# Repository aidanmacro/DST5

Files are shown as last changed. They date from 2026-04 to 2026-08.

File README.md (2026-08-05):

---
publishDate: YYYY-MM-DDT00:00:00Z

title: Low-Cost Breath Monitoring for Musicians Using the MYOSA Platform

excerpt: A portable, low-cost respiratory monitoring system for brass and wind musicians using the MYOSA development board, NDIR CO₂ sensing, and environmental measurements.

image: 

tags:
  - Embedded Systems
  - IoT
  - Music Technology
  - Respiratory Monitoring
  - MYOSA
---

> A low-cost embedded system providing objective, real-time respiratory feedback for musicians.

---

## Acknowledgements

---

## Overview

### Project Summary

### Problem Being Solved

### Project Objectives

---

## Demo / Examples

### Images

### Videos

---

## Features (Detailed)

### 1. MYOSA Embedded Platform

### 2. Breath Monitoring System

### 3. BMP180 Environmental Monitoring

### 4. Data Logging

### 5. User Interface

### 6. Low-Cost Design

### 7. Future Improvements

---

## Usage Instructions

### Hardware Setup

### Running the Software

### Example Code

## Tech Stack

---

## Requirements / Installation

### Hardware

### Software

## File Structure (Optional)

---

## License (Optional)

---

## Contribution Notes (Optional)

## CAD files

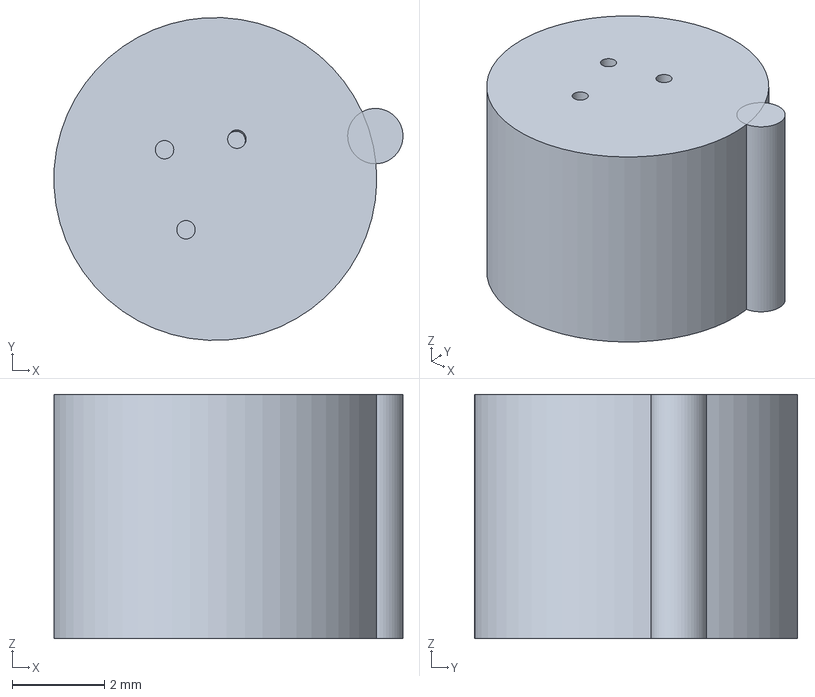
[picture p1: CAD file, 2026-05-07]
KiCAD/DST5_custom_library/3dmodels/TO46 Sheath.step
7.57 x 6.99 x 5.30 mm

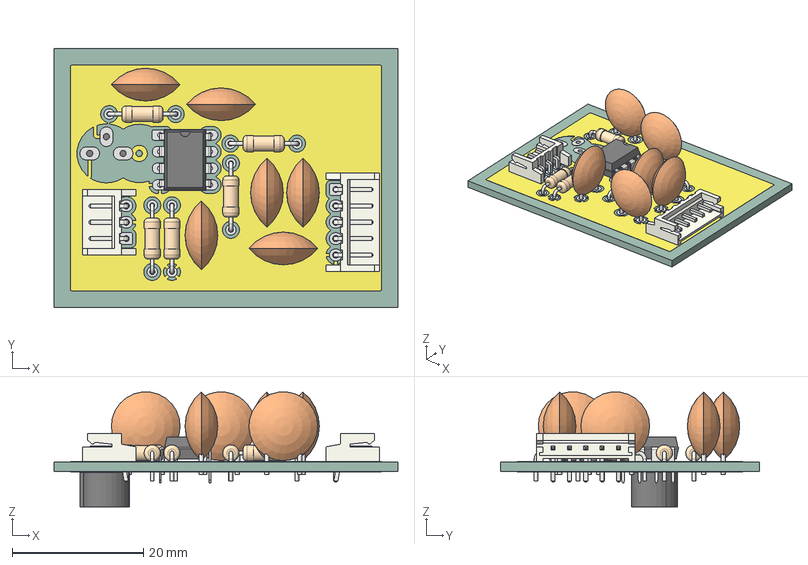
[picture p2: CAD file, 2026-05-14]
KiCAD/projects/photodiode TIA circuit/photodiode_tia_circuit/.step
52.5 x 39.5 x 17.5 mm
DIP-8_W7.62mm
JST_EH_S5B-EH_1x05_P2.50mm_Horizontal
C_Disc_D10.5mm_W5.0mm_P5.00mm x 6
R_Axial_DIN0207_L6.3mm_D2.5mm_P10.16mm_Horizontal x 5
JST_EH_S3B-EH_1x03_P2.50mm_Horizontal
TO46 Sheath
photodiode_tia_circuit_copper
photodiode_tia_circuit_pad
photodiode_tia_circuit_via
photodiode_tia_circuit_PCB

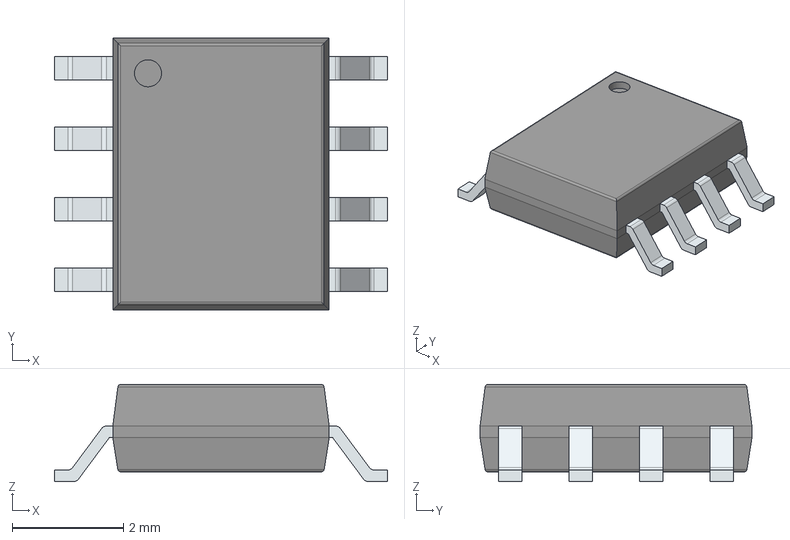
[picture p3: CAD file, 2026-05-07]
KiCAD/DST5_custom_library/3dmodels/STCS05DR.stp
6.00 x 4.90 x 1.75 mm
PinsArrayLR

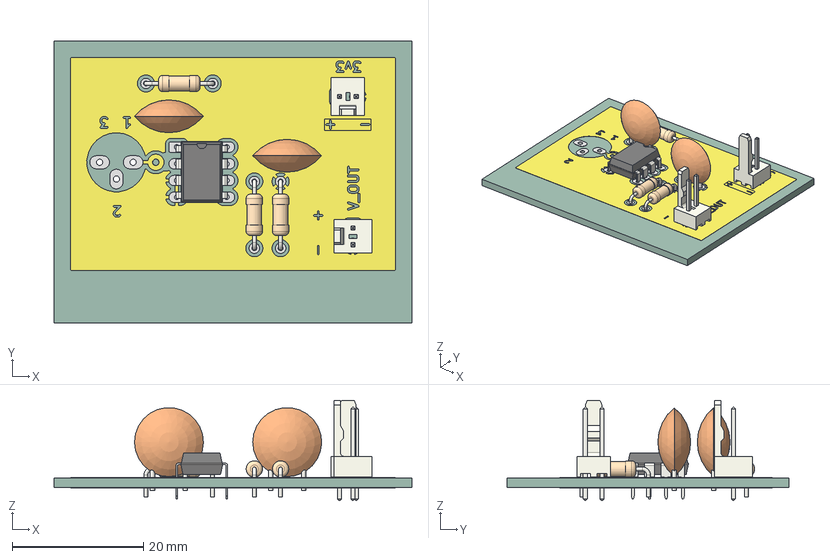
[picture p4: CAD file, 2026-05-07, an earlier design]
KiCAD/projects/photodiode TIA circuit/photodiode_tia_circuit/old_version.step
54.5 x 43.0 x 15.3 mm
DIP-8_W7.62mm
C_Disc_D10.5mm_W5.0mm_P5.00mm x 2
R_Axial_DIN0207_L6.3mm_D2.5mm_P10.16mm_Horizontal x 3
Molex_KK-254_AE-6410-02A_1x02_P2.54mm_Vertical x 2
photodiode_tia_circuit_copper
photodiode_tia_circuit_pad
photodiode_tia_circuit_via
photodiode_tia_circuit_PCB

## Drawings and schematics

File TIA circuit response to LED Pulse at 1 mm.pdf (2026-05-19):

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

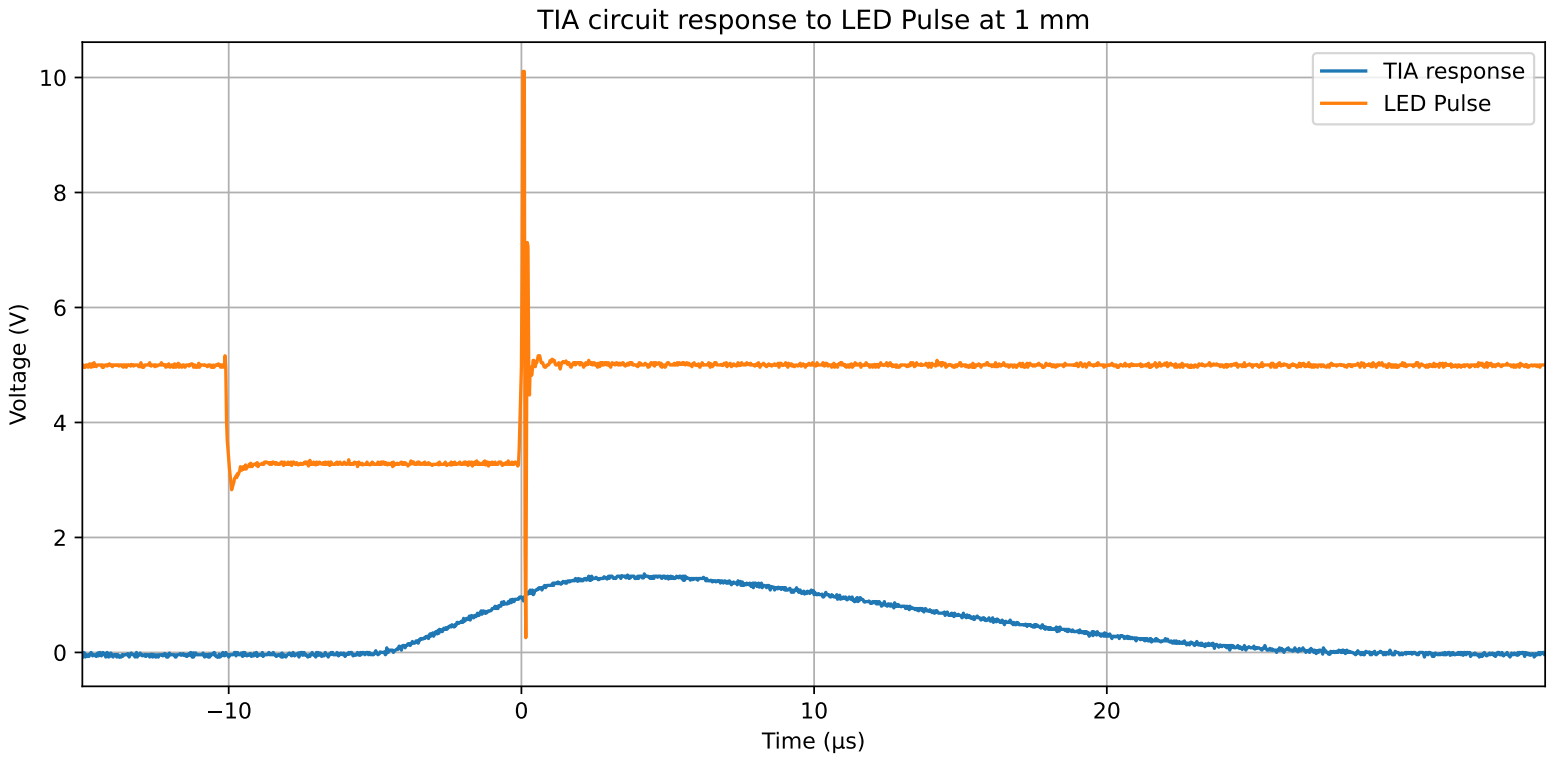
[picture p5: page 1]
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

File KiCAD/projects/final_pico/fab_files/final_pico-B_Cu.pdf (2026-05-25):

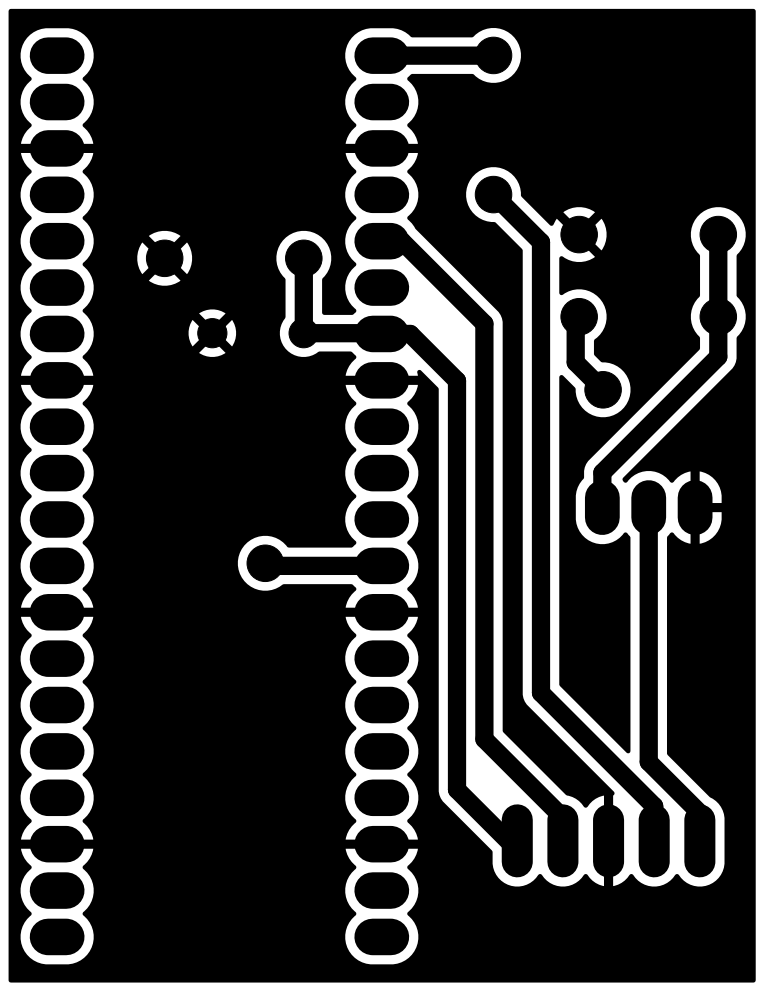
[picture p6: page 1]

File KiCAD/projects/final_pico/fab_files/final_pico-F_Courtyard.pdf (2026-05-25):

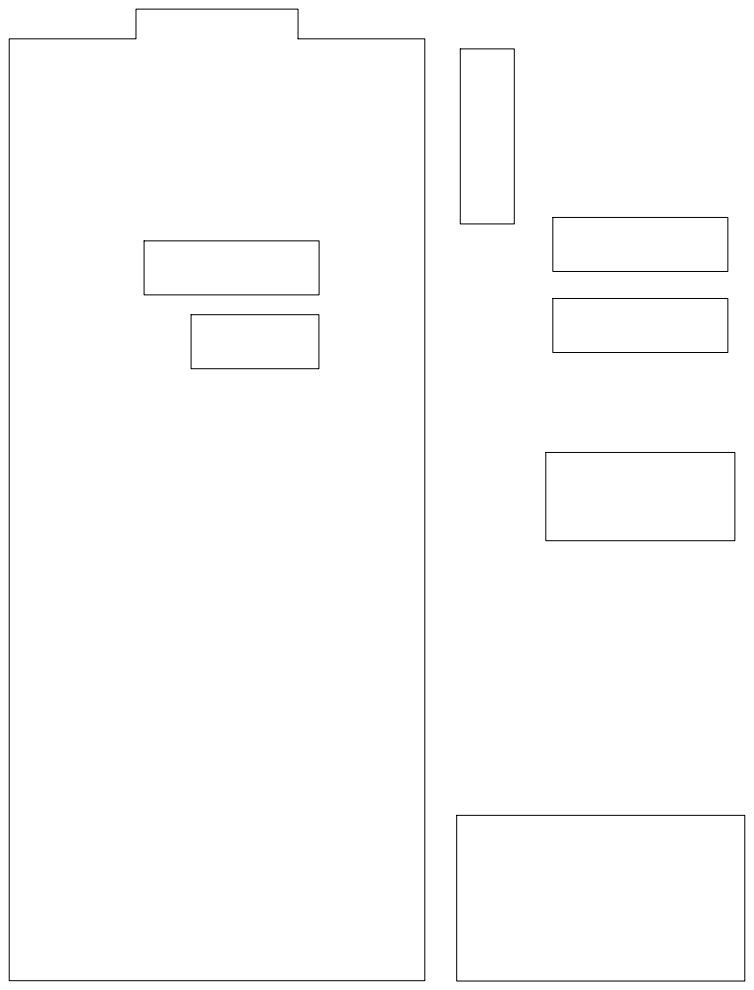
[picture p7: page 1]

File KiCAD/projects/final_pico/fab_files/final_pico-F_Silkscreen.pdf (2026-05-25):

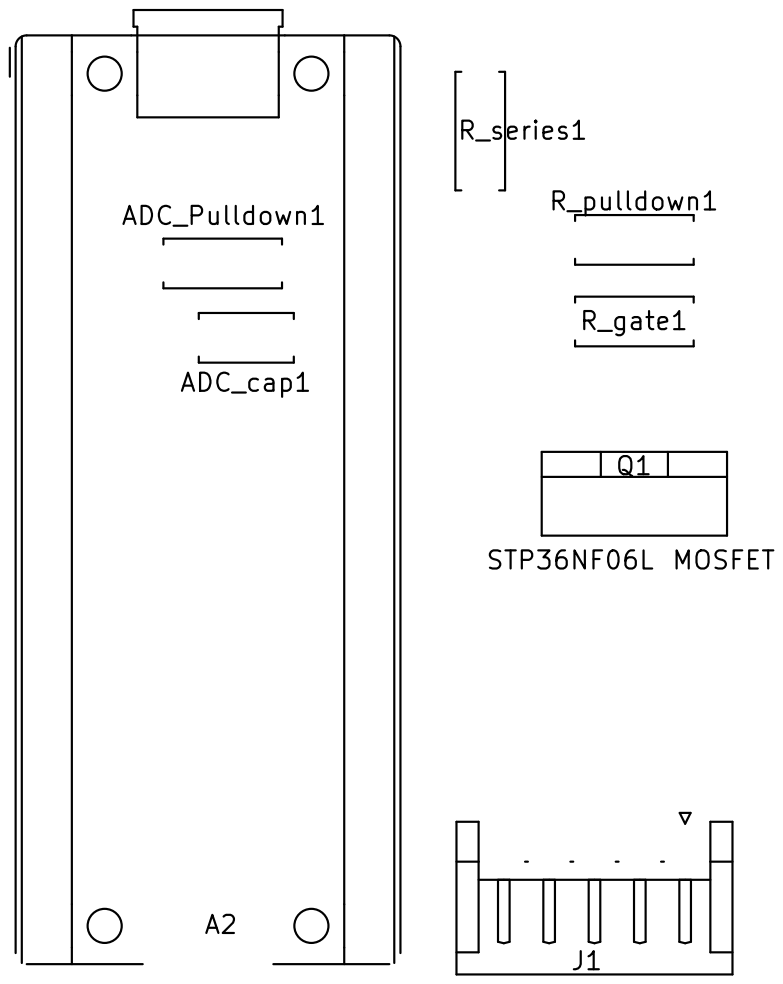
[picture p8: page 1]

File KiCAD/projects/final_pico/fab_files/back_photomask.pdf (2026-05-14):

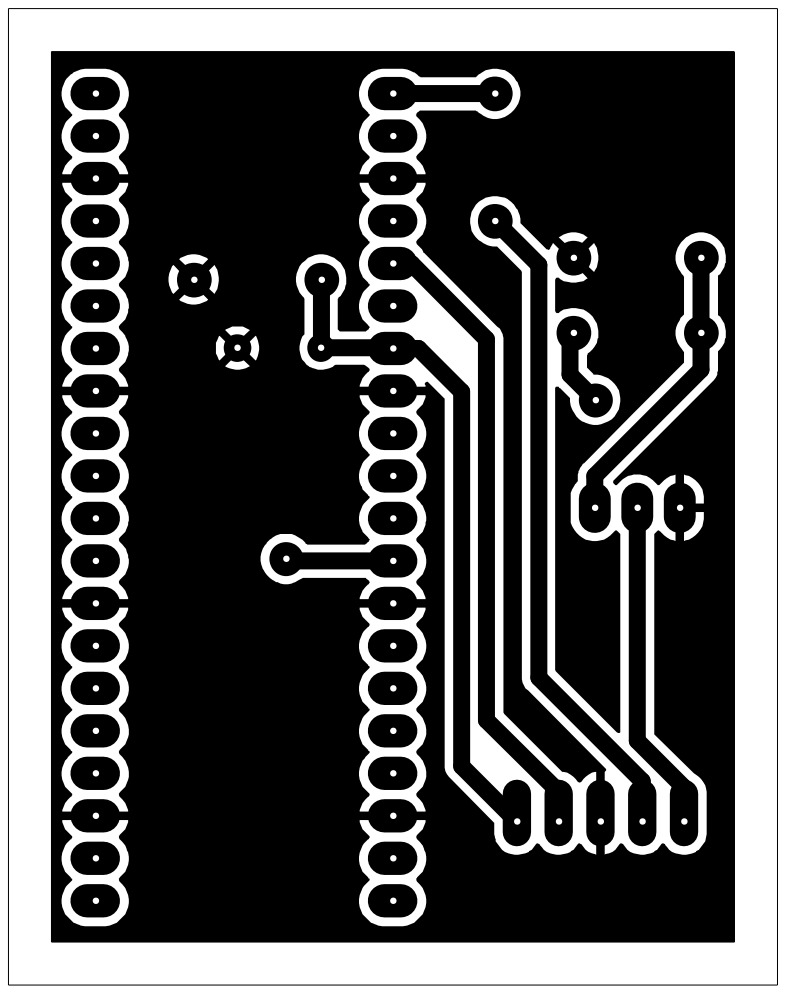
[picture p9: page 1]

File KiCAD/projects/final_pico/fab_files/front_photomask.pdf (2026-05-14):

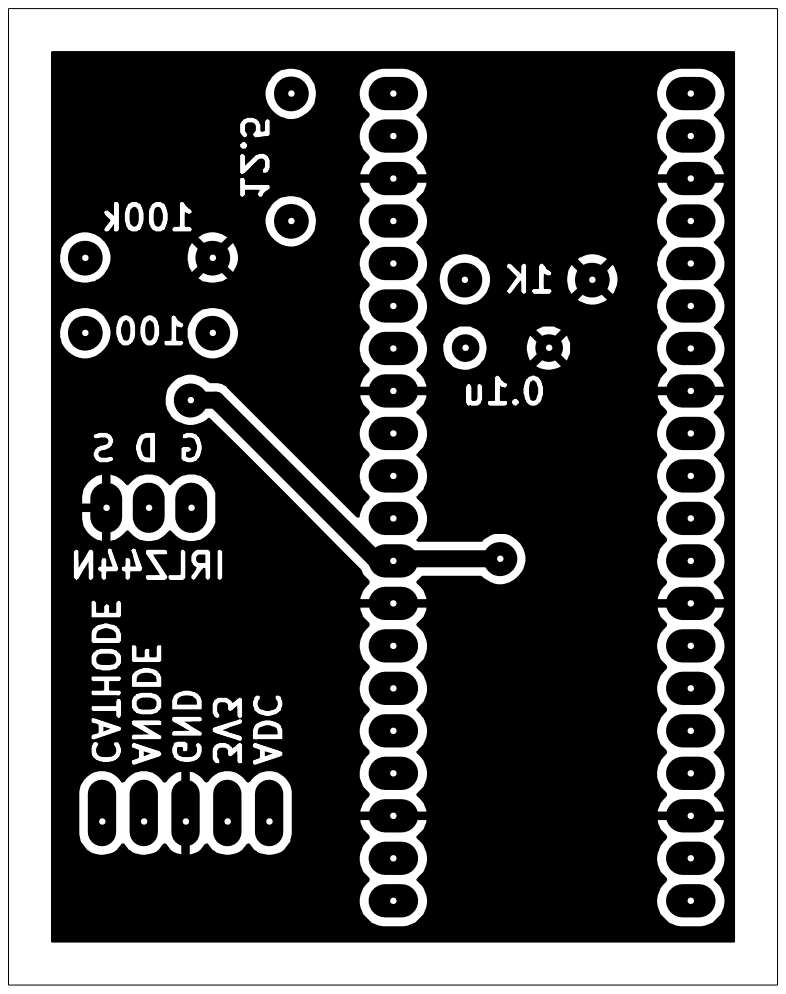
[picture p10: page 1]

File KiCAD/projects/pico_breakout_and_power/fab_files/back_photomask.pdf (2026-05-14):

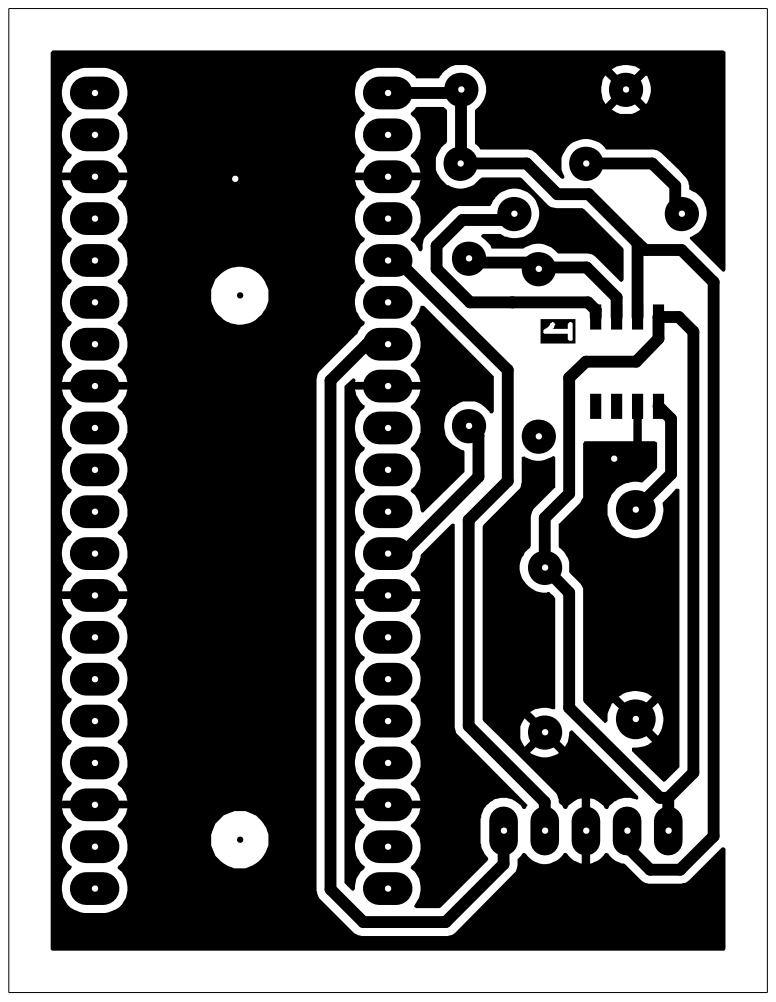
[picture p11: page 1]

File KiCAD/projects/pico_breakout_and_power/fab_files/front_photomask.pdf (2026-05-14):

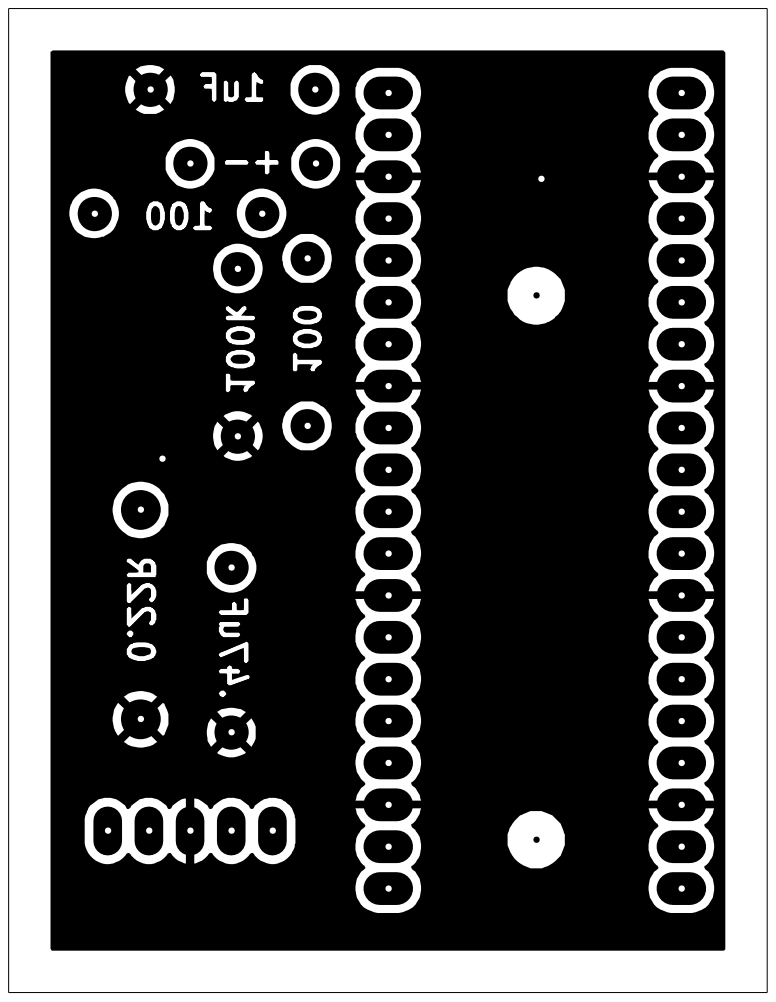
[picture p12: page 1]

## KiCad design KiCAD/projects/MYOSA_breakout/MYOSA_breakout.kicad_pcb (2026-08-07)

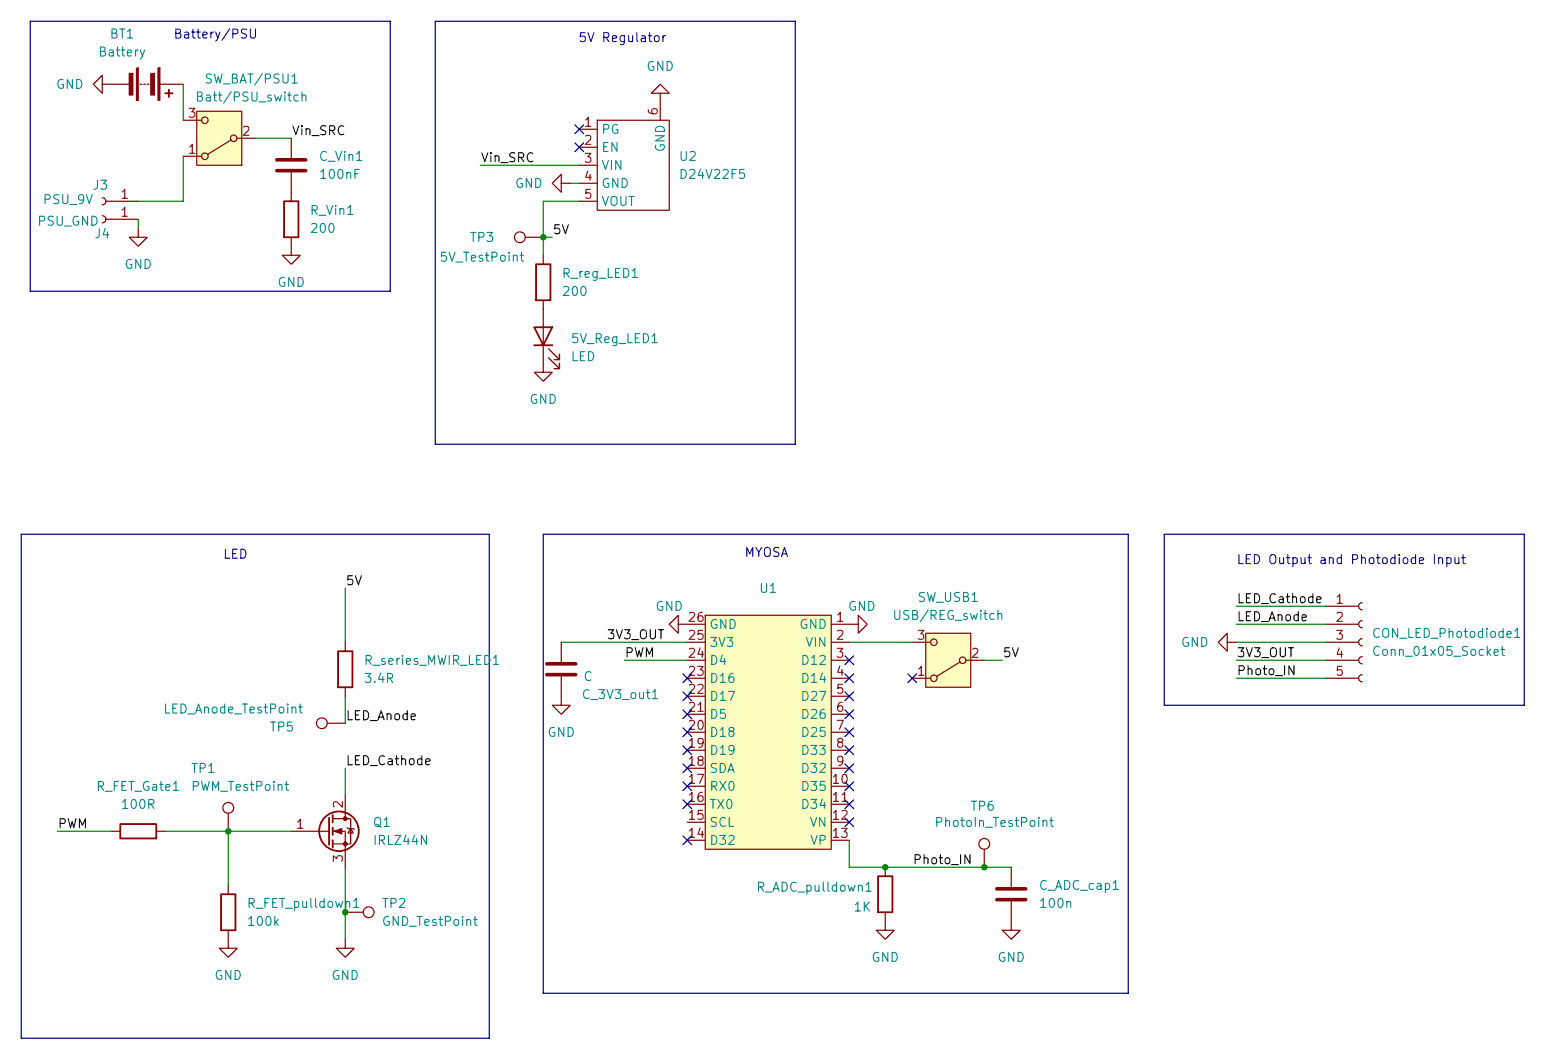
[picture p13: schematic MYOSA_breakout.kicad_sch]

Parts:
5V_Reg_LED1: LED; LED_D5.0mm
BT1: Battery; BatteryHolder_MPD_BA9VPC_1xPP3
CON_LED_Photodiode1: Conn_01x05_Socket; JST_EH_S5B-EH_1x05_P2.50mm_Horizontal
C_3V3_out1: C; C_Disc_D5.0mm_W2.5mm_P5.00mm
C_ADC_cap1: 100n; C_Disc_D5.0mm_W2.5mm_P5.00mm
C_Vin1: 100nF; C_Disc_D5.0mm_W2.5mm_P5.00mm
J3: PSU_9V; Banana_Jack_1Pin
J4: PSU_GND; Banana_Jack_1Pin
Q1: IRLZ44N; TO-220-3_Vertical
R_ADC_pulldown1: 1K; R_Axial_DIN0207_L6.3mm_D2.5mm_P7.62mm_Horizontal
R_FET_Gate1: 100R; R_Axial_DIN0207_L6.3mm_D2.5mm_P7.62mm_Horizontal
R_FET_pulldown1: 100k; R_Axial_DIN0207_L6.3mm_D2.5mm_P7.62mm_Horizontal
R_Vin1: 200; R_Axial_DIN0207_L6.3mm_D2.5mm_P7.62mm_Horizontal
R_reg_LED1: 200; R_Axial_DIN0207_L6.3mm_D2.5mm_P7.62mm_Horizontal
R_series_MWIR_LED1: 3.4R; R_Axial_DIN0207_L6.3mm_D2.5mm_P7.62mm_Horizontal
SW_BAT/PSU1: Batt/PSU_switch; SW_Slide-03_Wuerth-WS-SLTV_10x2.5x6.4_P2.54mm
SW_USB1: USB/REG_switch; SW_Slide-03_Wuerth-WS-SLTV_10x2.5x6.4_P2.54mm
TP1: PWM_TestPoint; TestPoint_Loop_D2.50mm_Drill1.85mm
TP2: GND_TestPoint; TestPoint_Loop_D2.50mm_Drill1.85mm
TP3: 5V_TestPoint; TestPoint_Loop_D2.50mm_Drill1.85mm
TP5: LED_Anode_TestPoint; TestPoint_Loop_D2.50mm_Drill1.85mm
TP6: PhotoIn_TestPoint; TestPoint_Loop_D2.50mm_Drill1.85mm
U1: MYOSA_ESP-32
U2: D24V22F5

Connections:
/3V3_OUT: CON_LED_Photodiode1.4, C_3V3_out1.1, U1.25 (3V3)
/5V: R_reg_LED1.1, R_series_MWIR_LED1.1, SW_USB1.2 (B), TP3.1, U2.5 (VOUT)
/LED_Anode: CON_LED_Photodiode1.2, R_series_MWIR_LED1.2, TP5.1
/LED_Cathode: CON_LED_Photodiode1.1, Q1.2 (D)
/PWM: R_FET_Gate1.1, U1.24 (D4)
/Photo_IN: CON_LED_Photodiode1.5, C_ADC_cap1.1, R_ADC_pulldown1.1, TP6.1, U1.13 (VP)
/Vin_SRC: C_Vin1.1, SW_BAT/PSU1.2 (B), U2.3 (VIN)
GND: 5V_Reg_LED1.1 (K), BT1.2 (-), CON_LED_Photodiode1.3, C_3V3_out1.2, C_ADC_cap1.2, J4.1, Q1.3 (S), R_ADC_pulldown1.2, R_FET_pulldown1.2, R_Vin1.2, TP2.1, U1.1 (GND), U1.26 (GND), U2.4 (GND), U2.6 (GND)
unnamed: 5V_Reg_LED1.2 (A), R_reg_LED1.2
unnamed: BT1.1 (+), SW_BAT/PSU1.3 (C)
unnamed: C_Vin1.2, R_Vin1.1
unnamed: J3.1, SW_BAT/PSU1.1 (A)
unnamed: Q1.1 (G), R_FET_Gate1.2, R_FET_pulldown1.1, TP1.1
unnamed: SW_USB1.3 (C), U1.2 (VIN)

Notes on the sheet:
LED
LED Output and Photodiode Input
MYOSA
Battery/PSU
5V Regulator

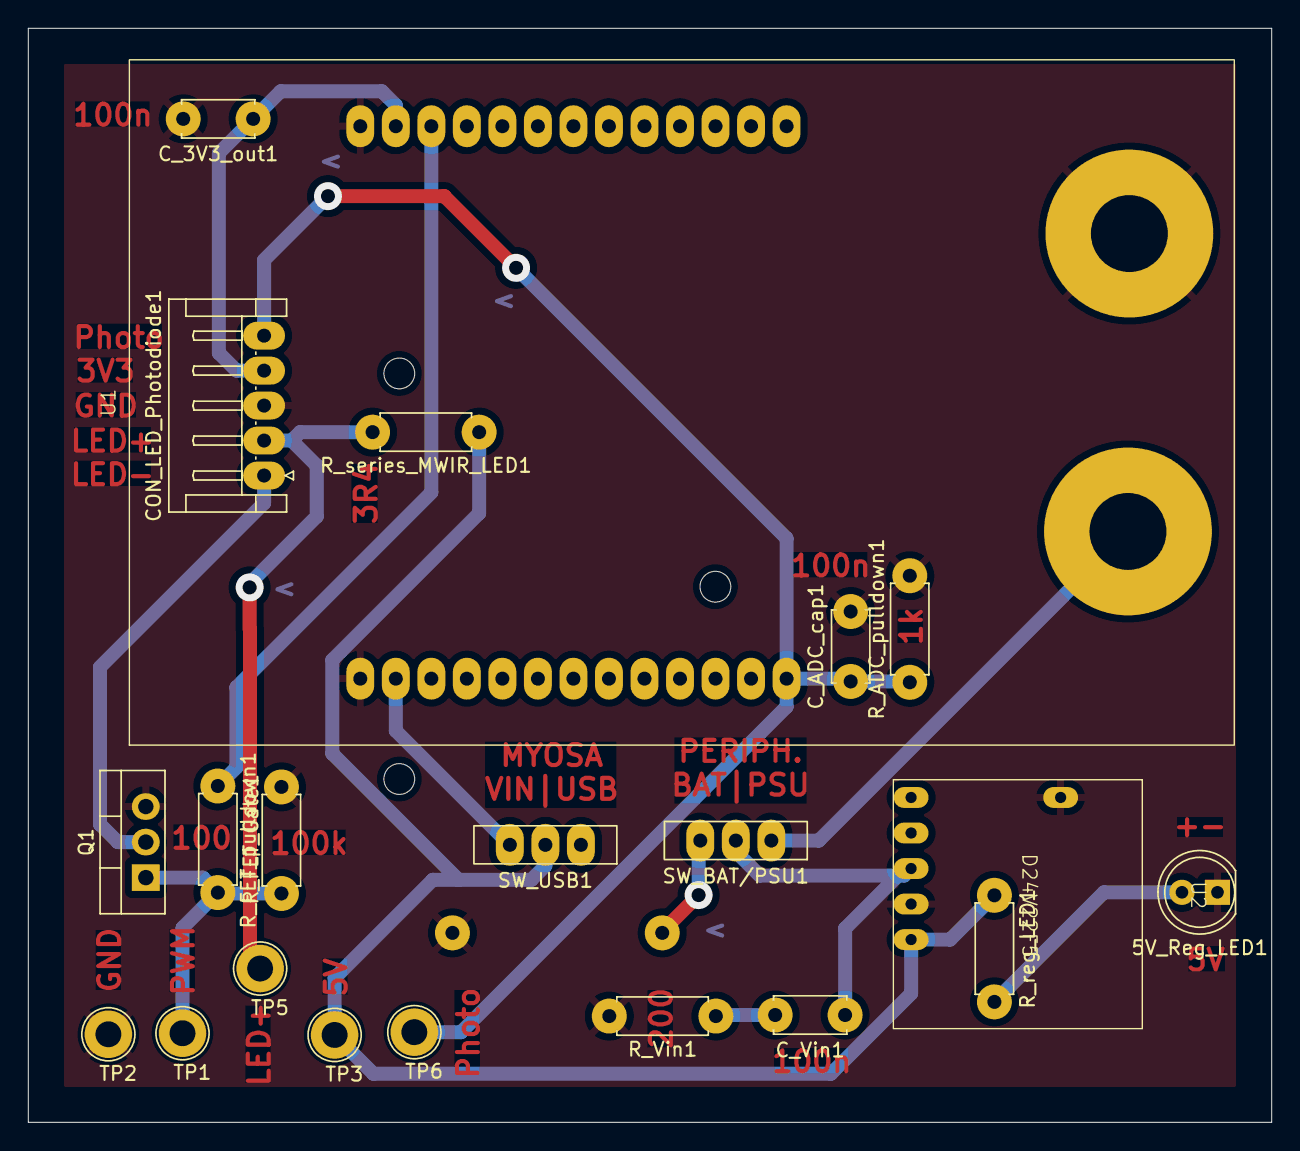
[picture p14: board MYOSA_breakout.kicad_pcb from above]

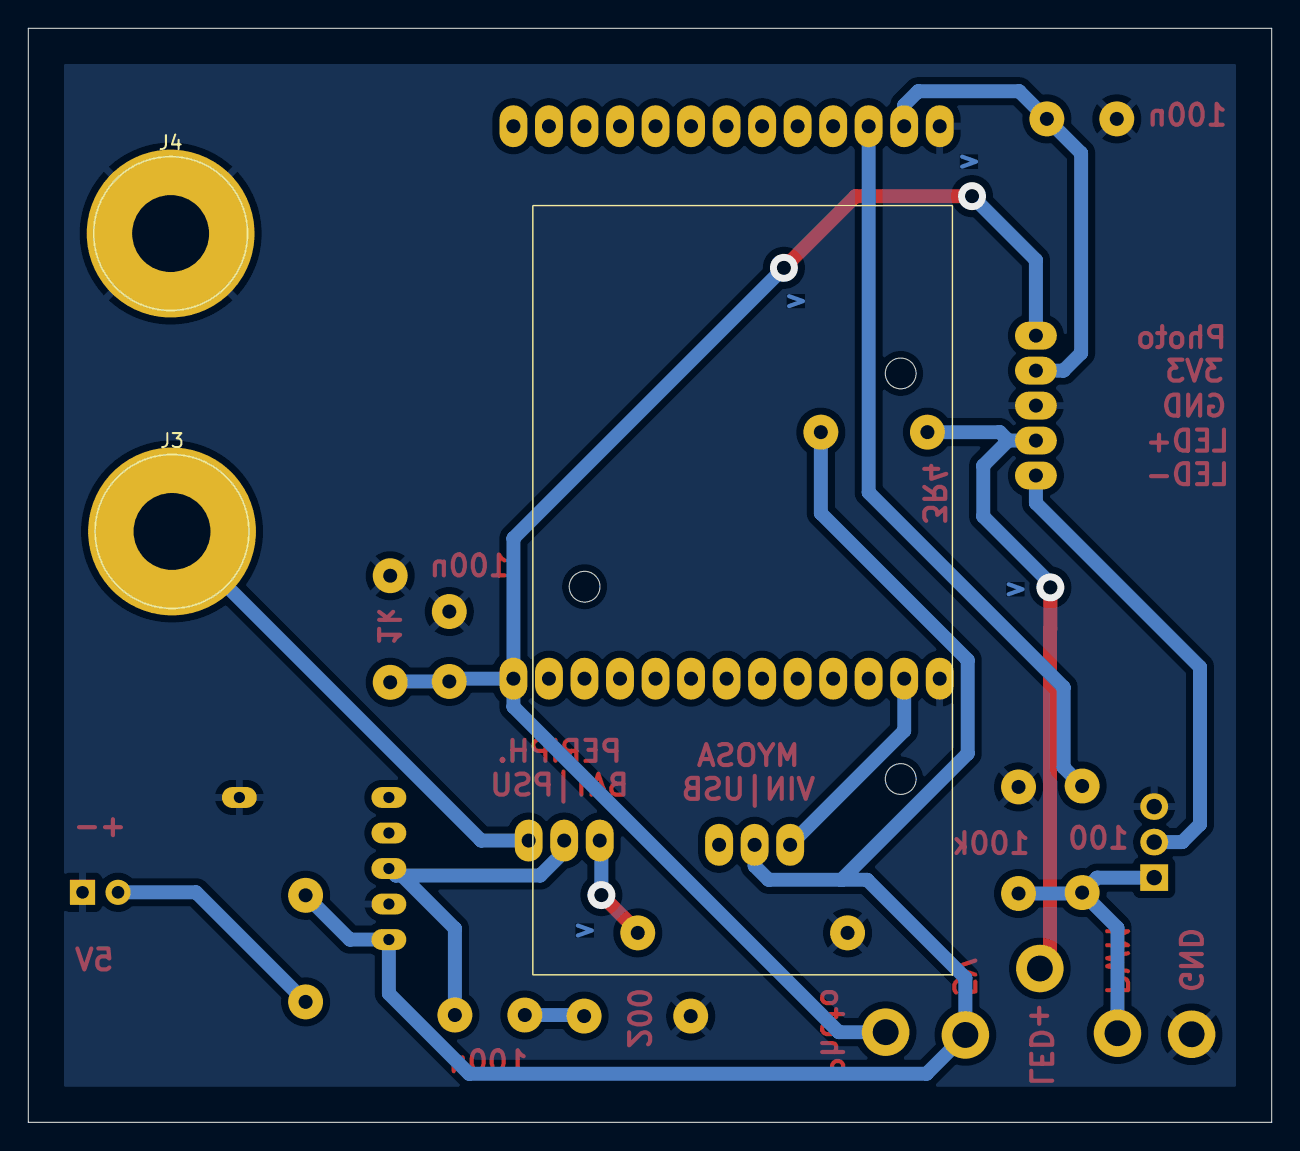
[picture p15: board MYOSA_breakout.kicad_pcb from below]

Board: 2 copper layers, 88.9 x 78.2 mm, 24 parts (3 on the bottom side), 14 nets.

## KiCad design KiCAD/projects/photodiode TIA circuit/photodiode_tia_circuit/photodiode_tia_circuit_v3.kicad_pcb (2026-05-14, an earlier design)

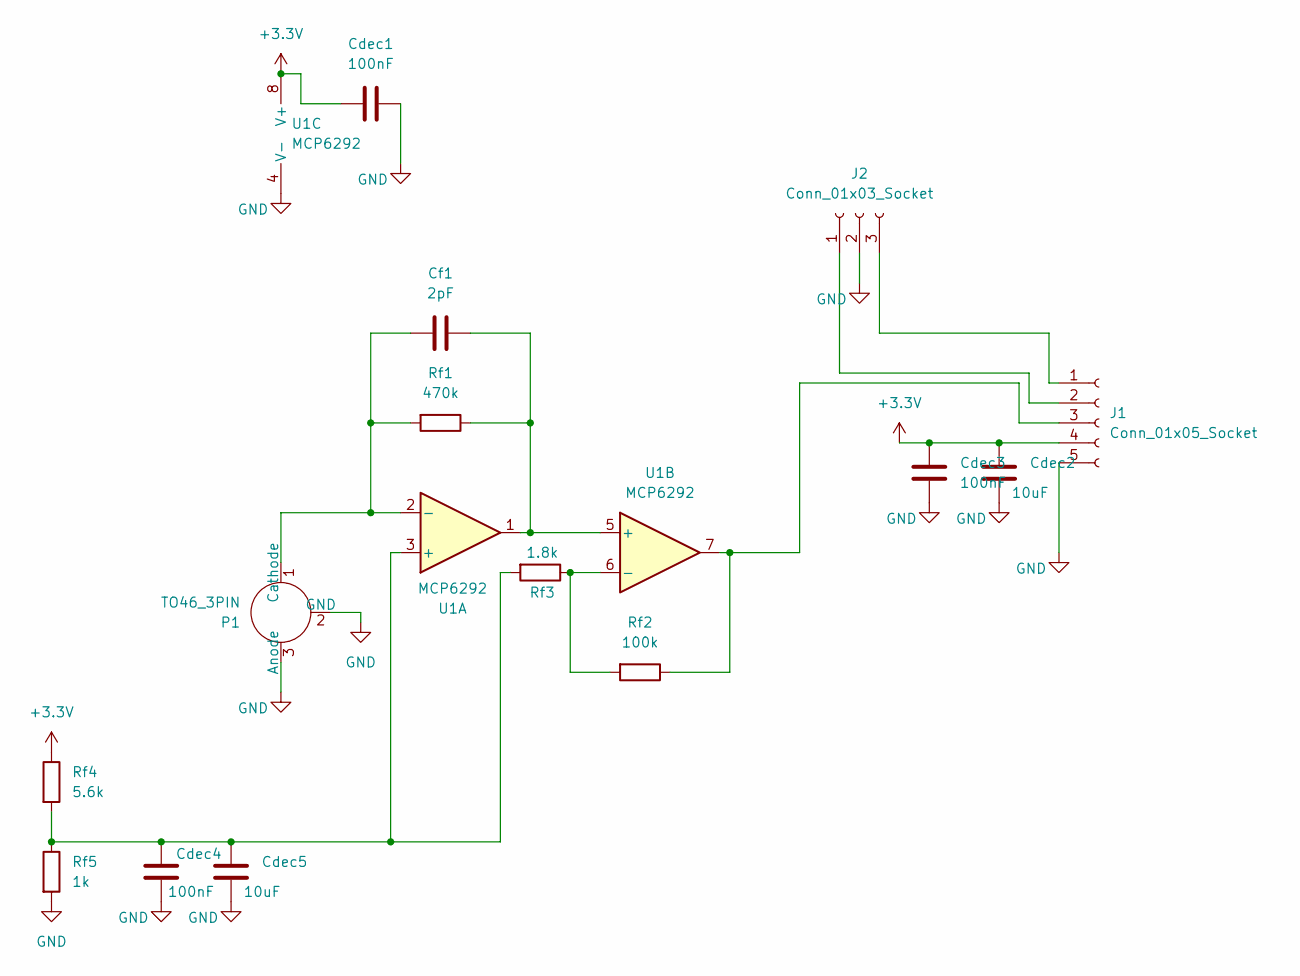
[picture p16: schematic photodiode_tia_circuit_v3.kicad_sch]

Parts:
Cdec1, Cdec3, Cdec4: 100nF; C_Disc_D10.5mm_W5.0mm_P5.00mm
Cdec2, Cdec5: 10uF; C_Disc_D10.5mm_W5.0mm_P5.00mm
Cf1: 2pF; C_Disc_D10.5mm_W5.0mm_P5.00mm
J1: Conn_01x05_Socket; JST_EH_S5B-EH_1x05_P2.50mm_Horizontal
J2: Conn_01x03_Socket; JST_EH_S3B-EH_1x03_P2.50mm_Horizontal
P1: TO46_3PIN
Rf1: 470k; R_Axial_DIN0207_L6.3mm_D2.5mm_P10.16mm_Horizontal
Rf2: 100k; R_Axial_DIN0207_L6.3mm_D2.5mm_P10.16mm_Horizontal
Rf3: 1.8k; R_Axial_DIN0207_L6.3mm_D2.5mm_P10.16mm_Horizontal
Rf4: 5.6k; R_Axial_DIN0207_L6.3mm_D2.5mm_P10.16mm_Horizontal
Rf5: 1k; R_Axial_DIN0207_L6.3mm_D2.5mm_P10.16mm_Horizontal
U1: MCP6292; DIP-8_W7.62mm_LongPads

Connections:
+3.3V: Cdec1.1, Cdec2.2, Cdec3.2, J1.4, Rf4.1, U1.8 (V+)
GND: Cdec1.2, Cdec2.1, Cdec3.1, Cdec4.1, Cdec5.1, J1.5, J2.2, P1.2 (GND), P1.3 (Anode), Rf5.2, U1.4 (V-)
unnamed: J1.1, J2.3
unnamed: J1.2, J2.1
unnamed: J1.3, Rf2.1, U1.7
unnamed: Cf1.1, P1.1 (Cathode), Rf1.2, U1.2 (-)
unnamed: Cdec4.2, Cdec5.2, Rf3.2, Rf4.2, Rf5.1, U1.3 (+)
unnamed: Cf1.2, Rf1.1, U1.1, U1.5 (+)
unnamed: Rf2.2, Rf3.1, U1.6 (-)

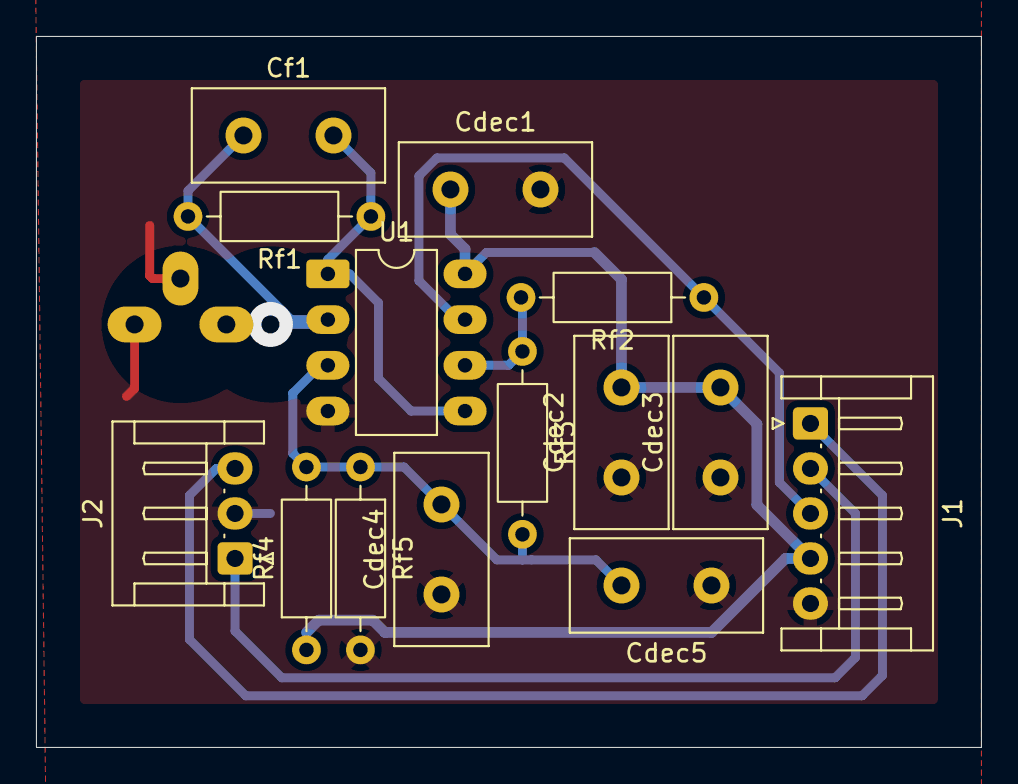
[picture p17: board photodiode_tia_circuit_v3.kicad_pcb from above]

Board: 2 copper layers, 52.5 x 39.5 mm, 15 parts (1 on the bottom side), 9 nets.

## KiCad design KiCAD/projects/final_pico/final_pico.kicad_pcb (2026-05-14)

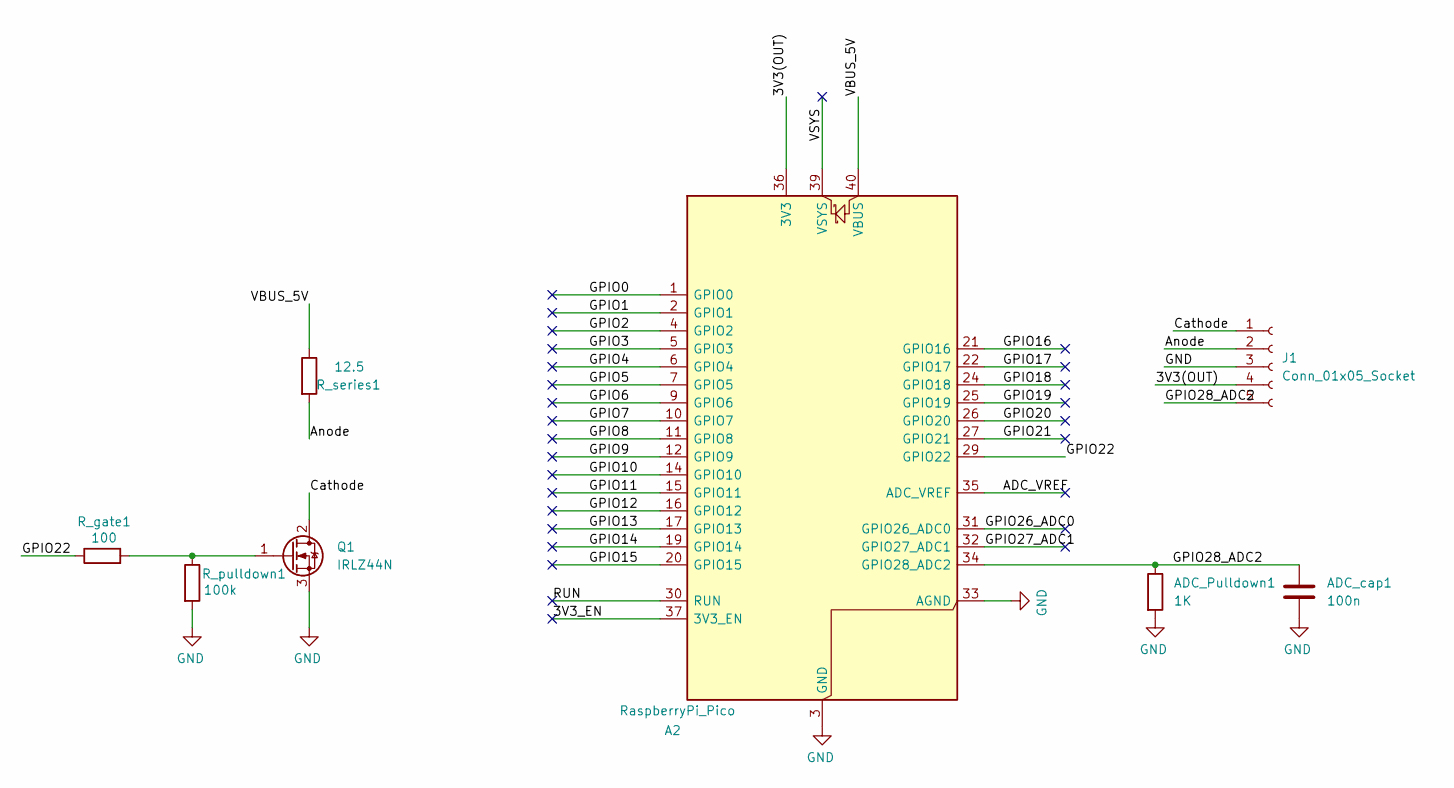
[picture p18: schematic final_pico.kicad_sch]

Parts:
A2: RaspberryPi_Pico; RaspberryPi_Pico_Common_THT
ADC_Pulldown1: 1K; R_Axial_DIN0207_L6.3mm_D2.5mm_P7.62mm_Horizontal
ADC_cap1: 100n; C_Disc_D5.0mm_W2.5mm_P5.00mm
J1: Conn_01x05_Socket; JST_EH_S5B-EH_1x05_P2.50mm_Horizontal
Q1: IRLZ44N; TO-220-3_Vertical
R_gate1: 100; R_Axial_DIN0207_L6.3mm_D2.5mm_P7.62mm_Horizontal
R_pulldown1: 100k; R_Axial_DIN0207_L6.3mm_D2.5mm_P7.62mm_Horizontal
R_series1: 12.5; R_Axial_DIN0207_L6.3mm_D2.5mm_P7.62mm_Horizontal

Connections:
/3V3(OUT): A2.36 (3V3), J1.4
/3V3_EN: A2.37 (3V3_EN)
/ADC_VREF: A2.35 (ADC_VREF)
/Anode: J1.2, R_series1.2
/Cathode: J1.1, Q1.2 (D)
/GPIO0: A2.1 (GPIO0)
/GPIO1: A2.2 (GPIO1)
/GPIO2: A2.4 (GPIO2)
/GPIO3: A2.5 (GPIO3)
/GPIO4: A2.6 (GPIO4)
/GPIO5: A2.7 (GPIO5)
/GPIO6: A2.9 (GPIO6)
/GPIO7: A2.10 (GPIO7)
/GPIO8: A2.11 (GPIO8)
/GPIO9: A2.12 (GPIO9)
/GPIO10: A2.14 (GPIO10)
/GPIO11: A2.15 (GPIO11)
/GPIO12: A2.16 (GPIO12)
/GPIO13: A2.17 (GPIO13)
/GPIO14: A2.19 (GPIO14)
/GPIO15: A2.20 (GPIO15)
/GPIO16: A2.21 (GPIO16)
/GPIO17: A2.22 (GPIO17)
/GPIO18: A2.24 (GPIO18)
/GPIO19: A2.25 (GPIO19)
/GPIO20: A2.26 (GPIO20)
/GPIO21: A2.27 (GPIO21)
/GPIO22: A2.29 (GPIO22), R_gate1.1
/GPIO26_ADC0: A2.31 (GPIO26_ADC0)
/GPIO27_ADC1: A2.32 (GPIO27_ADC1)
/GPIO28_ADC2: A2.34 (GPIO28_ADC2), ADC_Pulldown1.1, ADC_cap1.1, J1.5
/RUN: A2.30 (RUN)
/VBUS_5V: A2.40 (VBUS), R_series1.1
/VSYS: A2.39 (VSYS)
GND: A2.3 (GND), A2.8 (GND), A2.13 (GND), A2.18 (GND), A2.23 (GND), A2.28 (GND), A2.33 (AGND), A2.38 (GND), ADC_Pulldown1.2, ADC_cap1.2, J1.3, Q1.3 (S), R_pulldown1.2
unnamed: Q1.1 (G), R_gate1.2, R_pulldown1.1

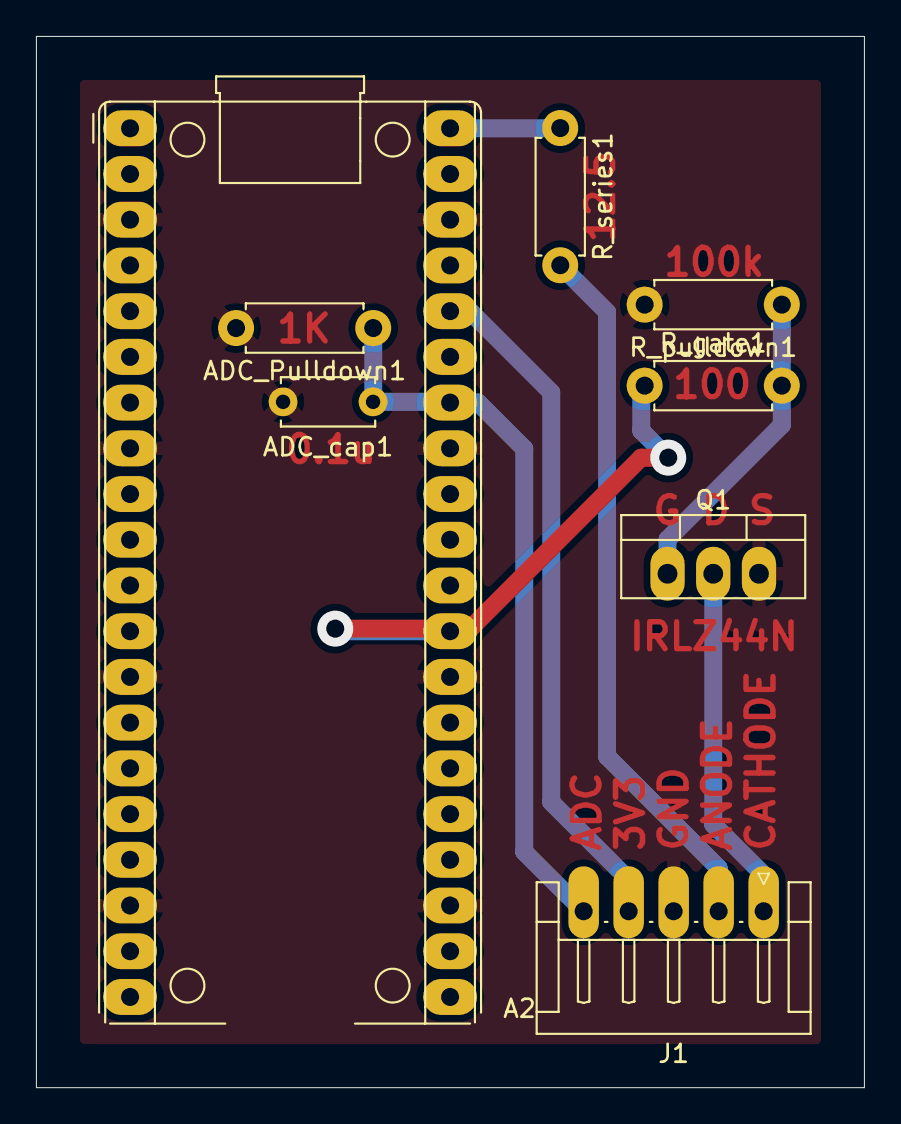
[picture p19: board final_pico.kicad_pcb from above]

Board: 2 copper layers, 46.0 x 58.4 mm, 8 parts (0 on the bottom side), 8 nets.

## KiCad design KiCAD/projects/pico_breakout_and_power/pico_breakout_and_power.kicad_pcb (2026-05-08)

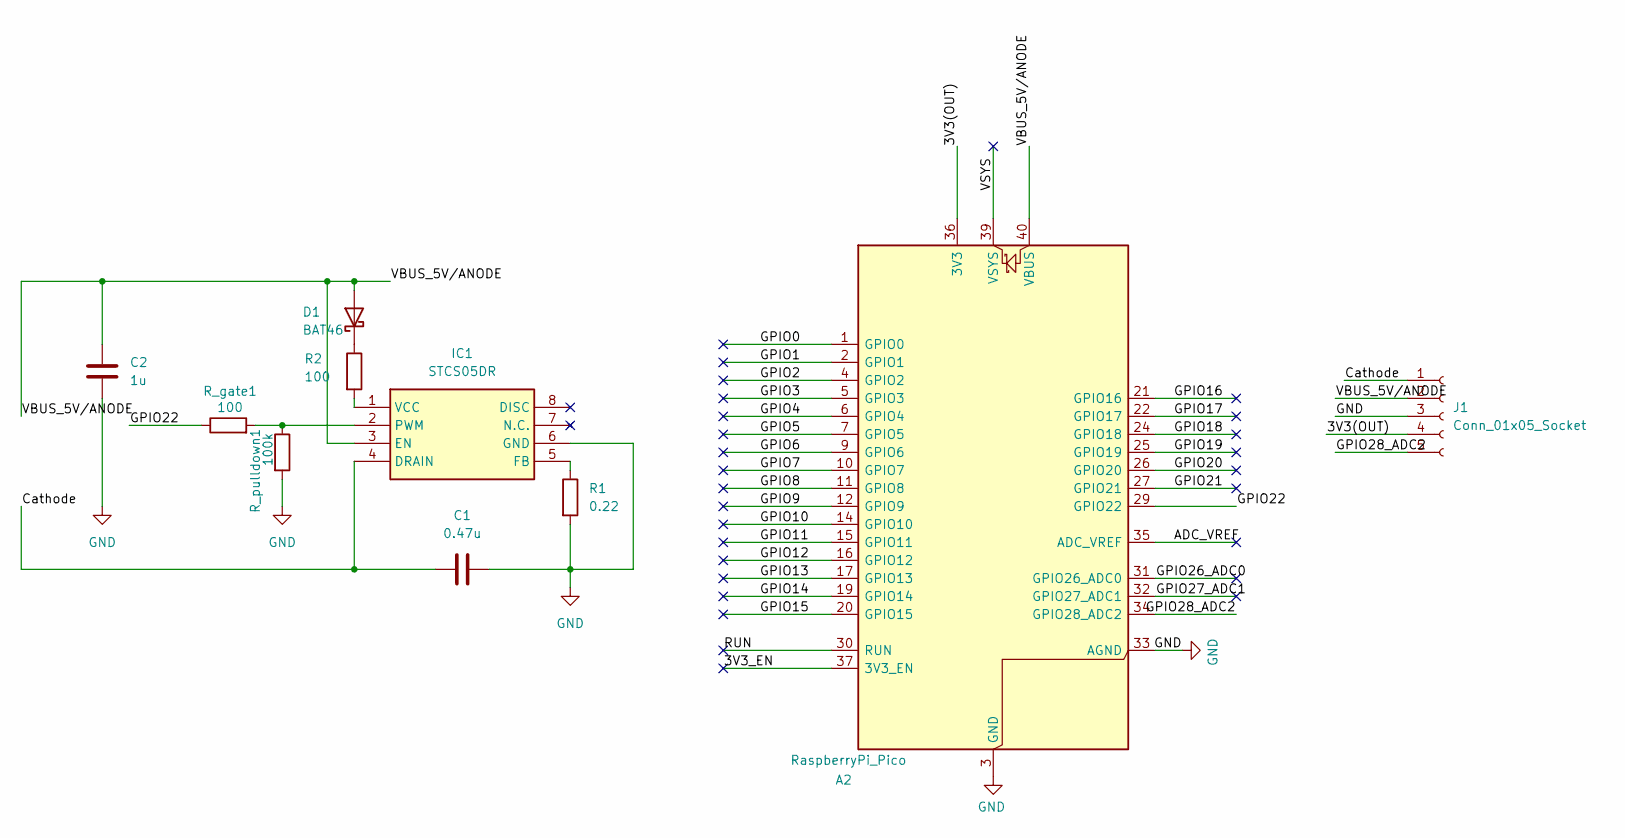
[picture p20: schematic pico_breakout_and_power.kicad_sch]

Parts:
A2: RaspberryPi_Pico; RaspberryPi_Pico_Common_THT
C1: 0.47u; C_Disc_D10.5mm_W5.0mm_P10.00mm
C2: 1u; C_Disc_D10.5mm_W5.0mm_P10.00mm
D1: BAT46; D_DO-35_SOD27_P7.62mm_Horizontal
IC1: STCS05DR; SOIC127P600X175-8N; Mouser Part Number 511-STCS05DR
J1: Conn_01x05_Socket; JST_EH_S5B-EH_1x05_P2.50mm_Horizontal
R1: 0.22; R_Axial_DIN0411_L9.9mm_D3.6mm_P12.70mm_Horizontal
R2: 100; R_Axial_DIN0207_L6.3mm_D2.5mm_P10.16mm_Horizontal
R_gate1: 100; R_Axial_DIN0207_L6.3mm_D2.5mm_P10.16mm_Horizontal
R_pulldown1: 100k; R_Axial_DIN0207_L6.3mm_D2.5mm_P10.16mm_Horizontal

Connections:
/3V3(OUT): A2.36 (3V3), J1.4
/3V3_EN: A2.37 (3V3_EN)
/ADC_VREF: A2.35 (ADC_VREF)
/Cathode: C1.1, IC1.4 (DRAIN), J1.1
/GPIO0: A2.1 (GPIO0)
/GPIO1: A2.2 (GPIO1)
/GPIO2: A2.4 (GPIO2)
/GPIO3: A2.5 (GPIO3)
/GPIO4: A2.6 (GPIO4)
/GPIO5: A2.7 (GPIO5)
/GPIO6: A2.9 (GPIO6)
/GPIO7: A2.10 (GPIO7)
/GPIO8: A2.11 (GPIO8)
/GPIO9: A2.12 (GPIO9)
/GPIO10: A2.14 (GPIO10)
/GPIO11: A2.15 (GPIO11)
/GPIO12: A2.16 (GPIO12)
/GPIO13: A2.17 (GPIO13)
/GPIO14: A2.19 (GPIO14)
/GPIO15: A2.20 (GPIO15)
/GPIO16: A2.21 (GPIO16)
/GPIO17: A2.22 (GPIO17)
/GPIO18: A2.24 (GPIO18)
/GPIO19: A2.25 (GPIO19)
/GPIO20: A2.26 (GPIO20)
/GPIO21: A2.27 (GPIO21)
/GPIO22: A2.29 (GPIO22), R_gate1.1
/GPIO26_ADC0: A2.31 (GPIO26_ADC0)
/GPIO27_ADC1: A2.32 (GPIO27_ADC1)
/GPIO28_ADC2: A2.34 (GPIO28_ADC2), J1.5
/RUN: A2.30 (RUN)
/VBUS_5V/ANODE: A2.40 (VBUS), C2.1, D1.2 (A), IC1.3 (EN), J1.2
/VSYS: A2.39 (VSYS)
GND: A2.3 (GND), A2.8 (GND), A2.13 (GND), A2.18 (GND), A2.23 (GND), A2.28 (GND), A2.33 (AGND), A2.38 (GND), C1.2, C2.2, IC1.6 (GND), J1.3, R1.2, R_pulldown1.2
unnamed: D1.1 (K), R2.1
unnamed: IC1.5 (FB), R1.1
unnamed: IC1.2 (PWM), R_gate1.2, R_pulldown1.1
unnamed: IC1.1 (VCC), R2.2

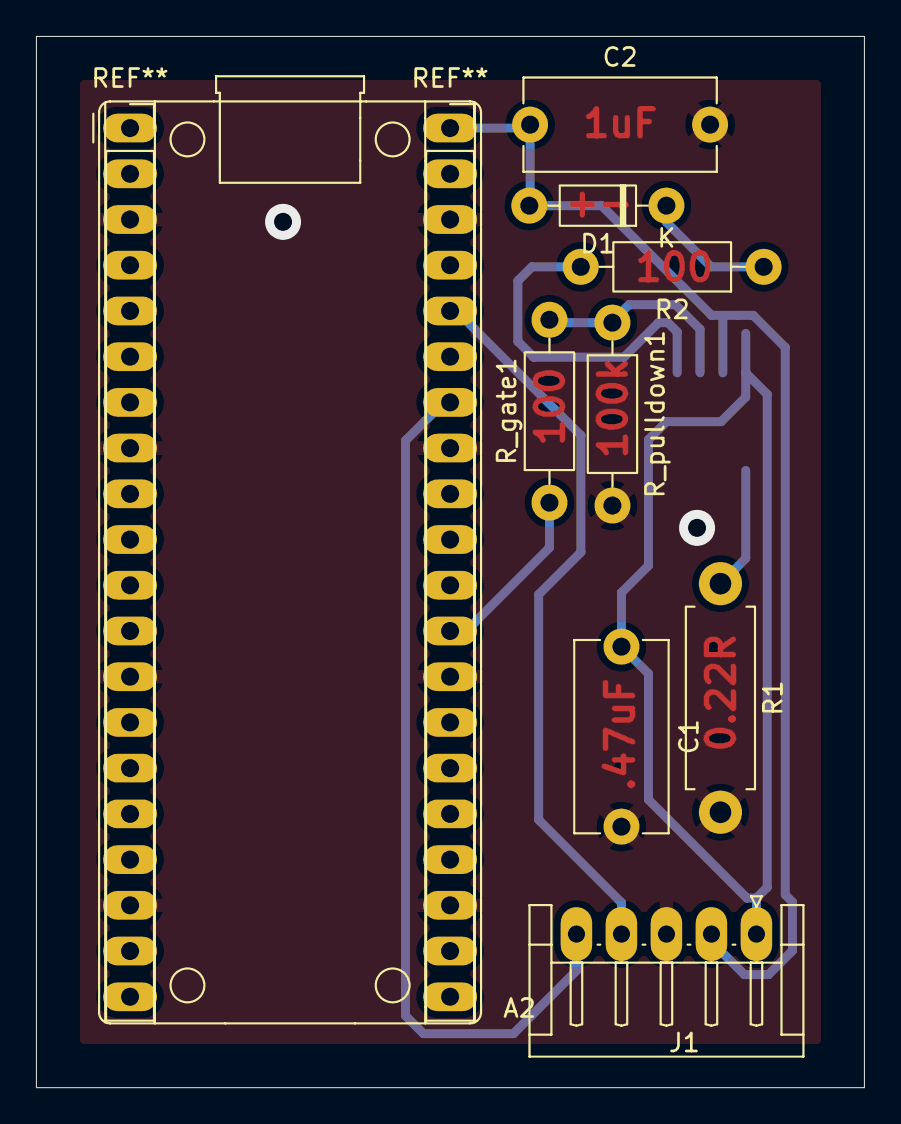
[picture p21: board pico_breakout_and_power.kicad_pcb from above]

Board: 2 copper layers, 46.0 x 58.4 mm, 10 parts (1 on the bottom side), 10 nets.

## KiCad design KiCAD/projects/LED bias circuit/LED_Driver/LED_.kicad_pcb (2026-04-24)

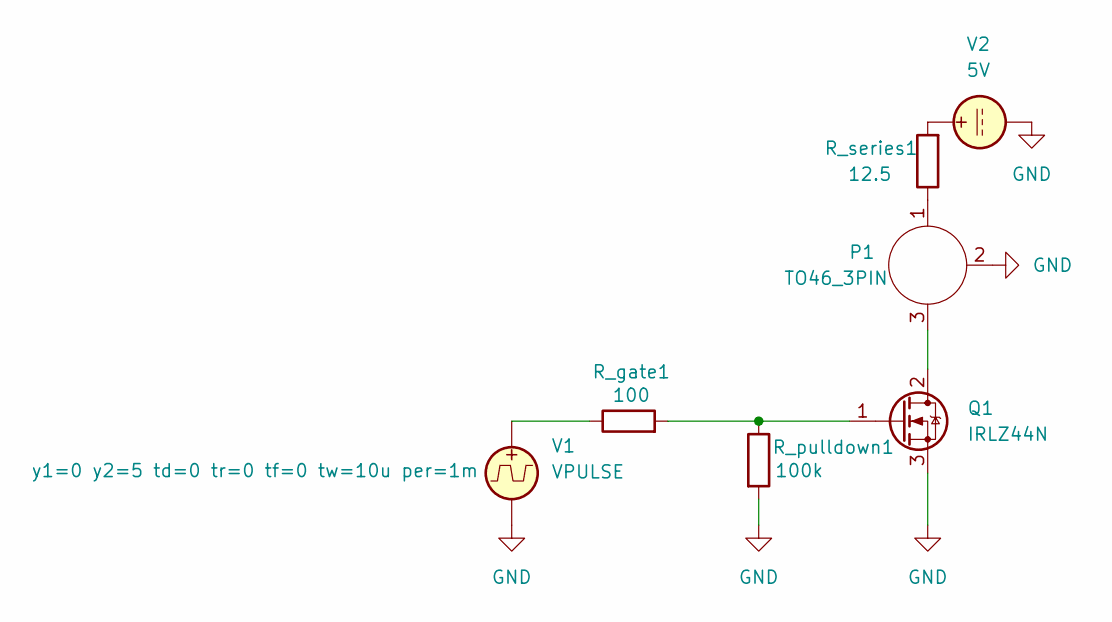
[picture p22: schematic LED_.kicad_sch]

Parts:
P1: TO46_3PIN
Q1: IRLZ44N; TO-220-3_Vertical
R_gate1: 100; R_Axial_DIN0207_L6.3mm_D2.5mm_P10.16mm_Horizontal
R_pulldown1: 100k; R_Axial_DIN0207_L6.3mm_D2.5mm_P10.16mm_Horizontal
R_series1: 12.5; R_Axial_DIN0207_L6.3mm_D2.5mm_P10.16mm_Horizontal
V1: VPULSE; TerminalBlock_Phoenix_MKDS-1,5-2-5.08_1x02_P5.08mm_Horizont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
V2: 5V; TerminalBlock_Phoenix_MKDS-1,5-2-5.08_1x02_P5.08mm_Horizont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

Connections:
GND: P1.2 (GND), Q1.3 (S), R_pulldown1.2, V1.2, V2.2
unnamed: P1.1 (Anode), R_series1.1
unnamed: P1.3 (Cathode), Q1.2 (D)
unnamed: Q1.1 (G), R_gate1.2, R_pulldown1.1
unnamed: R_gate1.1, V1.1
unnamed: R_series1.2, V2.1

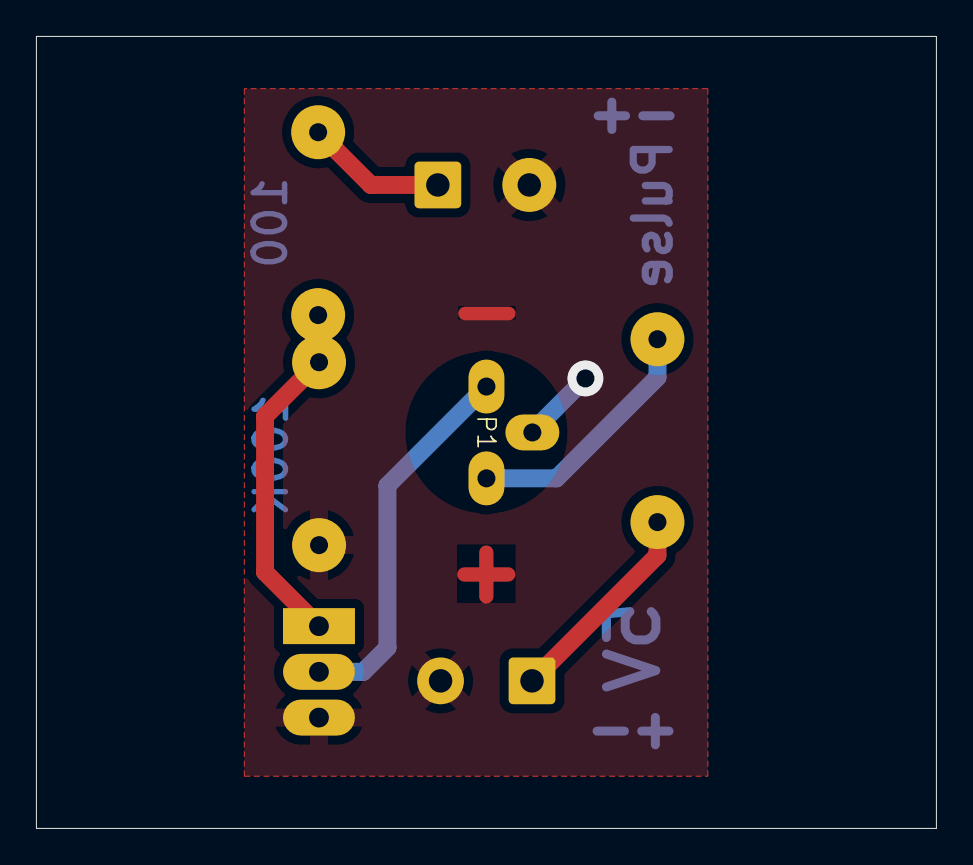
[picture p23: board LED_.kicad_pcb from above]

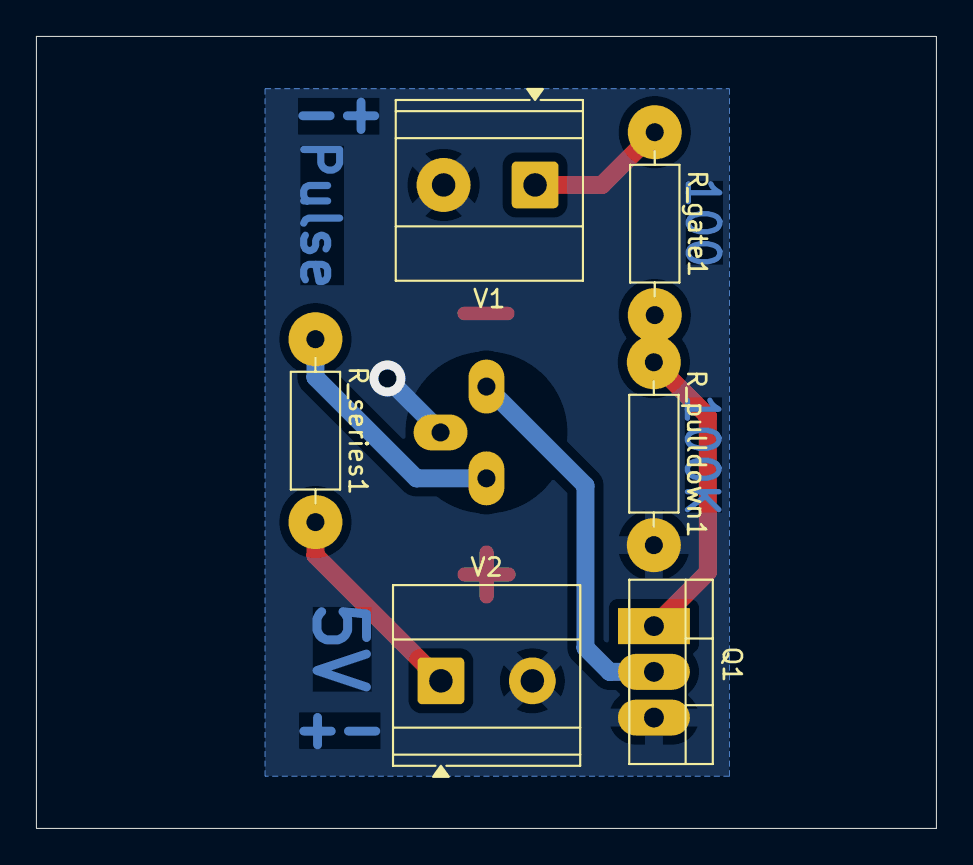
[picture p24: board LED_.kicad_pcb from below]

Board: 2 copper layers, 50.0 x 44.0 mm, 7 parts (6 on the bottom side), 6 nets.

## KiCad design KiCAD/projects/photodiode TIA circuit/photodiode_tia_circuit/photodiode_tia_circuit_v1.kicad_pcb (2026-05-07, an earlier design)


Board: 2 copper layers, 60.0 x 40.0 mm, 7 parts (0 on the bottom side), 4 nets.

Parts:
Cdec1: 100nF; C_Disc_D10.5mm_W5.0mm_P5.00mm
Cf1: DNP; C_Disc_D10.5mm_W5.0mm_P5.00mm
J_OUT1: Conn_01x02_Socket; Molex_KK-254_AE-6410-02A_1x02_P2.54mm_Vertical
J_PWR1: Conn_01x02_Socket; Molex_KK-254_AE-6410-02A_1x02_P2.54mm_Vertical
P1: TO46_3PIN
Rf1: 10M R; R_Axial_DIN0207_L6.3mm_D2.5mm_P10.16mm_Horizontal
U1: MCP6292; DIP-8_W7.62mm_LongPads

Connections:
+3.3V: Cdec1.1, J_PWR1.1
GND: Cdec1.2, J_OUT1.2, J_PWR1.2, P1.2 (GND), P1.3 (Anode), U1.3 (+), U1.4, U1.5, U1.6, U1.7
unnamed: Cf1.2, J_OUT1.1, Rf1.1, U1.1
unnamed: Cf1.1, P1.1 (Cathode), Rf1.2, U1.2 (-)

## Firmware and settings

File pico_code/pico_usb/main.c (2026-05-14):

#include <stdio.h>
#include <stdint.h>
#include <string.h>

#include <bsp/board_api.h>
#include <tusb.h>

#include <pico/stdio.h>
#include "pico/stdlib.h"
#include "hardware/adc.h"
#include "hardware/pwm.h"

#define PWM_PIN 22

#define ADC_GPIO 28
#define ADC_INPUT 2
#define BUFFER_SAMPLES 512

#define MAGIC1 0x5049434F  // "PICO"
#define MAGIC2 0x41444321  // "ADC!"

typedef struct __attribute__((packed)) {
    uint32_t magic1;
    uint32_t magic2;
    uint32_t sequence;
    uint16_t samples;
    uint16_t checksum;
} packet_header_t;

static uint16_t samples[BUFFER_SAMPLES];
static uint8_t tx_packet[sizeof(packet_header_t) + BUFFER_SAMPLES * sizeof(uint16_t)];
static uint32_t sequence_number = 0;

static uint16_t checksum_u16(const uint16_t *data, uint16_t n)
{
    uint32_t sum = 0;

    for (uint16_t i = 0; i < n; i++) {
        sum += data[i];
    }

    return (uint16_t)(sum & 0xFFFF);
}

static void setup_pwm_pulse(void)
{
    gpio_set_function(PWM_PIN, GPIO_FUNC_PWM);

    uint slice = pwm_gpio_to_slice_num(PWM_PIN);
    uint channel = pwm_gpio_to_channel(PWM_PIN);

    pwm_config config = pwm_get_default_config();

    // 1 kHz PWM: 125 MHz / 125 / 1000
    pwm_config_set_clkdiv(&config, 125.0f);
    pwm_config_set_wrap(&config, 1999);

    pwm_init(slice, &config, false);

    // 1% duty cycle
    pwm_set_chan_level(slice, channel, 20);

    pwm_set_enabled(slice, true);
}

static void cdc_write_chunks(uint8_t itf, const uint8_t *data, uint32_t len)
{
    const uint32_t chunk_size = 32;
    uint32_t sent = 0;

    while (sent < len) {
        tud_task();

        uint32_t chunk = len - sent;

        if (chunk > chunk_size) {
            chunk = chunk_size;
        }

        uint32_t written = tud_cdc_n_write(itf, data + sent, chunk);

        if (written > 0) {
            tud_cdc_n_write_flush(itf);
            sent += written;
        } else {
            for (int i = 0; i < 10; i++) {
                tud_task();
            }
        }
    }
}

void custom_cdc_task(void);

int main(void)
{
    board_init();
    tusb_init();

    if (board_init_after_tusb) {
        board_init_after_tusb();
    }

    stdio_init_all();

    setup_pwm_pulse();

    adc_init();
    adc_gpio_init(ADC_GPIO);
    adc_select_input(ADC_INPUT);

    while (1) {
        tud_task();
        custom_cdc_task();
    }

    return 0;
}

void custom_cdc_task(void)
{
    static absolute_time_t last_send_time;

    if (absolute_time_diff_us(last_send_time, get_absolute_time()) < 10000) {
        return;
    }

    last_send_time = get_absolute_time();

    for (uint16_t i = 0; i < BUFFER_SAMPLES; i++) {
        samples[i] = adc_read() & 0x0FFF;
    }

    packet_header_t header = {
        .magic1 = MAGIC1,
        .magic2 = MAGIC2,
        .sequence = sequence_number++,
        .samples = BUFFER_SAMPLES,
        .checksum = checksum_u16(samples, BUFFER_SAMPLES)
    };

    memcpy(tx_packet, &header, sizeof(header));
    memcpy(tx_packet + sizeof(header), samples, sizeof(samples));

    cdc_write_chunks(1, tx_packet, sizeof(tx_packet));
}

void tud_cdc_rx_cb(uint8_t itf)
{
    uint8_t buf[CFG_TUD_CDC_RX_BUFSIZE];
    uint32_t count = tud_cdc_n_read(itf, buf, sizeof(buf));
    (void)count;
}

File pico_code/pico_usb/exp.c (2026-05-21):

#include <stdio.h>
#include <stdint.h>
#include <stdbool.h>

#include <bsp/board_api.h>
#include <tusb.h>

#include <pico/stdio.h>
#include "pico/stdlib.h"
#include "hardware/adc.h"
#include "hardware/pwm.h"
#include "hardware/dma.h"
#include "hardware/irq.h"

#define PWM_PIN 22

#define ADC_GPIO 28
#define ADC_INPUT 2

#define BUFFER_SAMPLES 512
#define PACKET_BUFFERS 8

#define ADC_SAMPLE_RATE_HZ 500000

#define CDC_ITF 1

#define MAGIC1 0x5049434F
#define MAGIC2 0x41444321

typedef struct __attribute__((packed)) {
    uint32_t magic1;
    uint32_t magic2;
    uint32_t sequence;
    uint32_t dropped;
    uint16_t samples;
    uint16_t checksum;
} packet_header_t;

typedef struct {
    packet_header_t header;
    uint16_t samples[BUFFER_SAMPLES];
    volatile bool ready;
} packet_t;

static packet_t packets[PACKET_BUFFERS];

static volatile uint32_t sequence_number = 0;
static volatile uint32_t dropped_buffers = 0;

static volatile uint8_t write_index = 0;
static volatile uint8_t read_index = 0;

static volatile bool dma_running = false;

static int dma_chan;

static uint16_t checksum_u16(const uint16_t *data, uint16_t n)
{
    uint32_t sum = 0;

    for (uint16_t i = 0; i < n; i++) {
        sum += data[i];
    }

    return (uint16_t)(sum & 0xFFFF);
}

static void finish_packet(packet_t *packet)
{
    packet->header.magic1 = MAGIC1;
    packet->header.magic2 = MAGIC2;
    packet->header.sequence = sequence_number++;
    packet->header.dropped = dropped_buffers;
    packet->header.samples = BUFFER_SAMPLES;
    packet->header.checksum = checksum_u16(packet->samples, BUFFER_SAMPLES);

    packet->ready = true;

    write_index++;
    if (write_index >= PACKET_BUFFERS) {
        write_index = 0;
    }
}

static bool start_dma_capture(void)
{
    packet_t *packet = &packets[write_index];

    if (packet->ready) {
        dropped_buffers++;
        dma_running = false;
        return false;
    }

    dma_channel_set_read_addr(
        dma_chan,
        &adc_hw->fifo,
        false
    );

    dma_channel_set_write_addr(
        dma_chan,
        packet->samples,
        false
    );

    dma_channel_set_trans_count(
        dma_chan,
        BUFFER_SAMPLES,
        true
    );

    dma_running = true;

    return true;
}

static void dma_irq_handler(void)
{
    dma_hw->ints0 = 1u << dma_chan;

    dma_running = false;

    packet_t *packet = &packets[write_index];

    finish_packet(packet);

    start_dma_capture();
}

static void setup_pwm_pulse(void)
{
    gpio_set_function(PWM_PIN, GPIO_FUNC_PWM);

    uint slice = pwm_gpio_to_slice_num(PWM_PIN);
    uint channel = pwm_gpio_to_channel(PWM_PIN);

    pwm_config config = pwm_get_default_config();

    pwm_config_set_clkdiv(&config, 125.0f);
    pwm_config_set_wrap(&config, 1999);

    pwm_init(slice, &config, false);
    pwm_set_chan_level(slice, channel, 20);

    pwm_set_counter(slice, 0);
    pwm_set_enabled(slice, true);
}

static void setup_adc_dma(void)
{
    adc_init();
    adc_gpio_init(ADC_GPIO);
    adc_select_input(ADC_INPUT);

    adc_fifo_setup(
        true,
        true,
        1,
        false,
        false
    );

    float clkdiv = (48000000.0f / ADC_SAMPLE_RATE_HZ) - 1.0f;

    if (clkdiv < 0.0f) {
        clkdiv = 0.0f;
    }

    adc_set_clkdiv(clkdiv);

    adc_fifo_drain();

    dma_chan = dma_claim_unused_channel(true);

    dma_channel_config config = dma_channel_get_default_config(dma_chan);

    channel_config_set_transfer_data_size(&config, DMA_SIZE_16);
    channel_config_set_read_increment(&config, false);
    channel_config_set_write_increment(&config, true);
    channel_config_set_dreq(&config, DREQ_ADC);

    dma_channel_configure(
        dma_chan,
        &config,
        NULL,
        &adc_hw->fifo,
        BUFFER_SAMPLES,
        false
    );

    dma_channel_set_irq0_enabled(dma_chan, true);
    irq_set_exclusive_handler(DMA_IRQ_0, dma_irq_handler);
    irq_set_enabled(DMA_IRQ_0, true);

    start_dma_capture();

    adc_run(true);
}

static void maybe_restart_dma(void)
{
    if (!dma_running && !packets[write_index].ready) {
        start_dma_capture();
    }
}

static void cdc_write_chunks(uint8_t itf, const uint8_t *data, uint32_t len)
{
    const uint32_t chunk_size = 64;
    uint32_t sent = 0;

    while (sent < len) {
        tud_task();

        uint32_t chunk = len - sent;

        if (chunk > chunk_size) {
            chunk = chunk_size;
        }

        uint32_t written = tud_cdc_n_write(itf, data + sent, chunk);

        if (written > 0) {
            tud_cdc_n_write_flush(itf);
            sent += written;
        } else {
            for (int i = 0; i < 10; i++) {
                tud_task();
            }
        }
    }
}

void custom_cdc_task(void)
{
    packet_t *packet = &packets[read_index];

    if (!packet->ready) {
        maybe_restart_dma();
        return;
    }

    if (!tud_cdc_n_connected(CDC_ITF)) {
        maybe_restart_dma();
        return;
    }

    cdc_write_chunks(
        CDC_ITF,
        (const uint8_t *)&packet->header,
        sizeof(packet_header_t)
    );

    cdc_write_chunks(
        CDC_ITF,
        (const uint8_t *)packet->samples,
        BUFFER_SAMPLES * sizeof(uint16_t)
    );

    packet->ready = false;

    read_index++;
    if (read_index >= PACKET_BUFFERS) {
        read_index = 0;
    }

    maybe_restart_dma();
}

void tud_cdc_rx_cb(uint8_t itf)
{
    uint8_t buf[CFG_TUD_CDC_RX_BUFSIZE];
    uint32_t count = tud_cdc_n_read(itf, buf, sizeof(buf));
    (void)count;
}

int main(void)
{
    board_init();
    tusb_init();

    stdio_init_all();

    for (uint8_t i = 0; i < PACKET_BUFFERS; i++) {
        packets[i].ready = false;
    }

    setup_pwm_pulse();
    setup_adc_dma();

    while (1) {
        tud_task();
        custom_cdc_task();
    }

    return 0;
}

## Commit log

2026-04-22 First commit with custom 3-pin socker footprint and symbol.
2026-04-22 Create README.md for DST5 KiCad Library
    Add initial README with library information and setup instructions.
2026-04-24 Add project folder with LED circuit
    [LED_.kicad_pcb, LED_.kicad_sch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]
2026-04-29 edited tO46 symbol to be correct
    [photodiode_tia_circuit.kicad_pcb, photodiode_tia_circuit.kicad_sch]
2026-05-01 Fix size of TO46 socket
2026-05-06 New project for pico breakout board
    [pico_breakout_and_power.kicad_pcb, pico_breakout_and_power.kicad_sch]
2026-05-07 Add proper board edge
    [pico_breakout_and_power.kicad_pcb]
2026-05-07 manufacture documents and 3d model step file
    [.step, photodiode_tia_circuit.kicad_pcb, photodiode_tia_circuit.kicad_sch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]
2026-05-07 add pi pico footprint library as submodule
2026-05-07 Made grouped 3d model of pico with sockets
    [pico_breakout_and_power.kicad_pcb, pico_breakout_and_power.kicad_sch]
2026-05-07 Added new LED driver circuit design and associated KiCAD library files. to DST custom library.
    [LED Driver Circuit 2.0.kicad_pcb, LED Driver Circuit 2.0.kicad_sch]
2026-05-07 Added 3D files for the TO46 package to the custom DST library
    [TO46 Sheath.step]
2026-05-07 Fixed the weird holes in TO46 sheath 3D models, and the orientation too :p
    [TO46 Sheath.step]
2026-05-07 Added 3D model for the STCS05 driver to custom DST library
    [STCS05DR.stp]
2026-05-07 Combining pico and LED driver circuits
    [pico_breakout_and_power.kicad_pcb, pico_breakout_and_power.kicad_sch]
2026-05-08 Routed combined pico board
    [pico_breakout_and_power.kicad_pcb, pico_breakout_and_power.kicad_sch]
2026-05-08 First version of pico breakout submitted for manufacturing. Thicker traces and pads
    [pico_breakout_and_power.kicad_pcb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]
2026-05-09 Made simulation of TIA circuit
    [.kicad_sch, .kicad_sch.kicad_sch, photodiode_tia_circuit_simulation.kicad_sch]
2026-05-09 Update to make more sense and have flat-topped pulses
    [photodiode_tia_circuit_simulation.kicad_sch]
2026-05-09 Better yet sim
    [photodiode_tia_circuit_simulation.kicad_sch]
2026-05-09 removed history tracking
    [photodiode_tia_circuit_simulation.kicad_sch]
2026-05-09 even better sims
    [photodiode_tia_circuit_simulation.kicad_sch]
2026-05-11 Corrected photomasks for pico pcb
2026-05-11 latest version
    [.step, old_version.step, photodiode_tia_circuit.kicad_pcb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]
2026-05-12 Add C code to generate pulse, monitor adc, and send data via usb on pico. Also Python code to plot it in realtime on different device
2026-05-14 final C scripts for pico code and external python plotting
2026-05-14 Stop tracking .history folders
    [.kicad_sch, .kicad_sch.kicad_sch, .step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]
2026-05-14 Refreshing repo
    [.kicad_sch, .kicad_sch.kicad_sch, .step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]
2026-05-14 Deleting copy
    [.kicad_sch, pico_breakout_and_power.kicad_sch]
2026-05-14 Final Pico breakout board.
    [final_pico.kicad_pcb, final_pico.kicad_sch, pico_breakout_and_power.kicad_pcb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]
2026-05-18 Cmake files for pico code
2026-05-19 latest TIA
    [photodiode_TIA_Circuit_v4.kicad_pcb, photodiode_tia_circuit_v3.kicad_pcb, photodiode_tia_circuit_v3.kicad_sch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]
2026-05-19 Added code for plotting csvs from scopes, and refined pico and realtime plotting code further.
2026-05-25 final pcb cleanups
    [mosfet_switch.kicad_sch]
2026-08-04 MYOSA schematic
    [MYOSA_breakout.kicad_pcb, MYOSA_breakout.kicad_sch]
2026-08-04 MYOSA skeleton PCB
    [MYOSA_breakout.kicad_pcb, MYOSA_breakout.kicad_sch]
2026-08-04 MYOSA PCB v1
    [MYOSA_breakout.kicad_pcb, MYOSA_breakout.kicad_sch]
2026-08-05 KiCAD Updates + Manufacturing
    [MYOSA_breakout.kicad_pcb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]
2026-08-07 Change pad properties of banana plugs and battery holder to be larger
    [MYOSA_breakout.kicad_pcb]
2026-08-07 Increase pad size of hardware connector
    [MYOSA_breakout.kicad_pcb]
2026-08-10 New notes file to track testing of assembled board
2026-08-11 test code for PWM on MYOSA
